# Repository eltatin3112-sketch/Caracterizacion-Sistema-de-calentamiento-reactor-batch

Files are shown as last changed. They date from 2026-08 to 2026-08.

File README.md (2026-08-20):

# CARACTERIZACIÓN TÉRMICA Y SINTONIZACIÓN PID DEL REACTOR BATCH - GRUPO 5
## Identificación Experimental Térmica y Dinámica de Sistemas - Sistemas de Control II (UNET)

Elaborado por: Daniel Torres y Yermey Castro

---

### 1. OBJETIVO DEL PROYECTO DE CARACTERIZACIÓN TÉRMICA
Este repositorio documenta la caracterización del lazo de calentamiento de un Reactor Batch a escala. Su objetivo es emular el acondicionamiento térmico de una mezcla farmacéutica utilizando una resistencia de inmersión de 110V AC.

El objetivo de esta fase en *Sistemas de Control II* es identificar experimentalmente los parámetros termodinámicos de la planta (Ganancia `K`, Constante de Tiempo `Tau` y Tiempo Muerto `Theta`) aplicando el método de la curva de reacción en lazo abierto. Estos datos son obligatorios para el posterior diseño y sintonización de un controlador PID que permita estabilizar el proceso de forma 

---

### 2. Hardware Mínimo Requerido

| Componente | Referencia / Modelo | Cantidad | Función en el sistema |
| :--- | :--- | :--- | :--- |
| **Microcontrolador** | ESP32 DevKit V1 | 1 | Procesamiento, temporización del SSR y servidor web. |
| **Sensor Térmico** | Sonda DS18B20 | 1 | Medición digital de temperatura en el fluido. |
| **Actuador Térmico**| Resistencia Inmersión | 1 | Aporte calórico (800W nominales). |
| **Interfaz Potencia**| Relé Estado Sólido SSR-50DA | 1 | Conmutación rápida de los 110V AC. |
| **Acoplamiento DC** | Transistor NPN 2N2222 | 1 | Interfaz de disparo de baja corriente para proteger el ESP32. |
| **Resistencias** | 4.7kΩ y 220Ω | 1 c/u | Pull-up para bus de datos (4.7k) y límite de base (220R). |
| **Fuentes de Poder** | ATX de PC y Cargador 5V| 1 c/u | ATX entrega 5V al SSR. Cargador aísla la lógica del ESP32. |

---

### 3. TABLA DE CONEXIONES Y PINOUT (CABLEADO CON ACOPLAMIENTO DE POTENCIA)
| Origen | Señal / Pin | Destino Hardware | Notas Técnicas de Conexión |
| :--- | :--- | :--- | :--- |
| ESP32 | `3V3` | DS18B20 `VCC` | Alimentación de sonda (Cable rojo). |
| ESP32 | `GPIO 04` | DS18B20 `DATA`| Bus One-Wire (Cable amarillo/azul). **Requiere R de 4.7kΩ a 3V3.** |
| ESP32 | `GPIO 18` | Transistor `Base`| Señal de disparo de calor (A través de R de 220Ω). |
| Transistor | `Emisor` | **GND COMÚN** | Pata izquierda hacia tierra. |
| Transistor | `Colector`| SSR `Pin 4 (-)`| Pata derecha. Disparo lógico (Conmuta el negativo). |
| Fuente ATX | `+5V` (Rojo) | SSR `Pin 3 (+)` | Alimenta el SSR directamente con 5V, evitando cargar al ESP32. |
| Red 110V AC | `Fase (Línea)` | SSR `Pin 1 (Load)` | Interrupción de la red de corriente alterna (Tras pasar por fusible). |
| SSR | `Pin 2 (Load)` | Resistencia | Retorno de fase conmutada hacia el calentador. |
| Red 110V AC | `Neutro` | Resistencia | Cierre del circuito AC directo al tomacorriente. |

*Nota sobre "Aislamiento":* El uso del transistor 2N2222 sirve como etapa de acoplamiento de corriente (driver) para evitar caídas de tensión en los pines del ESP32. Dado que el Emisor del transistor comparte el GND del ESP32 y de la fuente ATX, **no existe aislamiento galvánico en el lado de DC**, pero la electrónica de baja tensión queda protegida por el aislamiento óptico interno que posee el propio módulo SSR-50 DA respecto al lado de 110V AC.

*(El diagrama eléctrico detallado en formato .fzz de Fritzing se encuentra dentro de la carpeta `Diagrama electrico Caracterizacion temperatura` de este repositorio).*
---

### 4. Cómo Descargar, Instalar y Ejecutar desde Cero

### A. Preparación y Compilación
1. Descargue este repositorio (Botón **"Code" -> "Download ZIP"**) o clónelo vía Git.
2. Abra la carpeta en **Visual Studio Code** con la extensión **PlatformIO** instalada.
3. Asegúrese de que el archivo `platformio.ini` esté en la raíz e incluya las librerías `OneWire` y `DallasTemperature`.
4. Conecte el ESP32, abra la terminal de PIO y ejecute la carga del firmware:
   `pio run --target upload`

### B. Puesta en Marcha (¡Precaución!)
1. **Llene el reactor con al menos 2 Litros de agua ANTES de continuar.**
2. Enchufe la etapa de control (ESP32 a 5V). 
3. *Solo después de validar el nivel de agua*, enchufe la clavija de 110V AC a la pared.
4. Conéctese a la red WiFi **Reactor_Batch_G5** (`control_industrial`) e ingrese a **`http://192.168.4.1`**.
5. Desde la HMI, varíe la potencia térmica y monitorice la gráfica.
---

### 5. VALIDACIÓN DE LIBRERÍAS LOCALES (MODO OFFLINE)
Para garantizar el funcionamiento del banco de pruebas en entornos industriales o laboratorios sin acceso a internet (como los de la UNET), las librerías de visualización y exportación se cargan directamente desde la memoria interna del ESP32 (LittleFS).

Al ingresar a la interfaz en tu navegador (`192.168.4.1`), verifique el estado en la sección de diagnóstico:
*   **Chart.js local:** cargado
*   **SheetJS local (XLSX):** cargado
*   **Modo offline:** OK

*Nota:* Si alguna librería aparece como "no cargado", asegúrese de haber ejecutado con éxito el comando `uploadfs` en el Paso 3 de la sección anterior.

---

### 6. PROCEDIMIENTO DEL ENSAYO DE CARACTERIZACIÓN TÉRMICA (LAZO ABIERTO)
Este protocolo experimental se ejecutó en **Lazo Abierto** (sin algoritmo de control automático en el ESP32, operando de forma manual la potencia del SSR al 100%) para capturar las curvas de reacción térmicas y analizar los gradientes del fluido:

#### Etapa 1: Ensayos de Homogeneidad Espacial (Sensor en 3 Profundidades)
Para comprobar si la agitación mecánica es efectiva para eliminar los gradientes térmicos, se realizaron tres pruebas secuenciales idénticas bajo una carga de 2 Litros de agua y agitación constante al 50% de PWM, moviendo la altura del sensor DS18B20:
1.  **Prueba A (Fondo):** Fijar la sonda al fondo del tanque (cerca de la resistencia). Resultado: Alcanzó los 40C en **2:51 minutos**.
2.  **Prueba B (Zona Media):** Fijar la sonda en el centro geométrico del fluido. Resultado: Alcanzó los 40C en **2:48 minutos**.
3.  **Prueba C (Superficie):** Fijar la sonda cerca de la superficie del agua. Resultado: Alcanzó los 40C en **2:42 minutos**.
*   **Análisis de Homogeneidad:** La diferencia de apenas **9 segundos** entre el punto más lento y el más rápido valida que la mezcla forzada homogeneiza la temperatura, aproximando el reactor al modelo de parámetros concentrados (mezcla perfecta).

#### Etapa 2: Ensayo de Convección Natural (Motor al 0%) vs. Forzada (Motor al 100%)
1.  **Convección Natural (Motor al 0%):** Con el agitador apagado, aplicar un escalón del 100% de potencia térmica y registrar la curva de temperatura.
2.  **Convección Forzada (Motor al 100%):** Con el motor a máxima velocidad (255 PWM), aplicar el mismo escalón y registrar la curva.
*   **Análisis:** Se demostró que al incrementar la velocidad de agitación se reduce el tiempo muerto (Theta) y disminuye la constante de tiempo (Tau), ya que aumenta el coeficiente global de transferencia de calor (U).

#### Etapa 3: Ensayo de Variación de Masa Térmica (Efecto de Carga)
1.  Cargar el reactor con **3 Litros de agua** (agitación al 100% PWM).
2.  Aplicar un escalón del 100% de calor, registrar la curva de temperatura y descargar el archivo de datos.
*   **Análisis:** Al aumentar el volumen un 50%, la constante de tiempo (Tau) aumentó un 46% (pasando de 92s a 135s), demostrando que la inercia térmica es altamente sensible a la masa del fluido.

---

### 7. PROYECCIÓN AL DISEÑO DEL CONTROLADOR PID EN MATLAB
Los datos crudos recolectados en estos ensayos en lazo abierto permitieron modelar matemáticamente la planta y calcular los parámetros del controlador que se implementarán en la fase de control automático (Tema 4):

*   **Parámetros FOPDT Identificados (Caso 2 Litros):** 
    *   Ganancia (K): 0.18 grados/%.
    *   Constante de tiempo (Tau): 92 segundos.
    *   Tiempo Muerto (Theta): 6 segundos.
*   **Cálculo Teórico de Cohen-Coon:**
    *   **Ganancia Proporcional (Kp):** 114.7
    *   **Tiempo Integral (Ti):** 14.6 segundos
    *   **Tiempo Derivativo (Td):** 2.1 segundos
*   **Sintonización Fina y Simulación en MATLAB:**
    Al simular el modelo teórico en MATLAB, se identificó que la ganancia de 114.7 causaba un sobreimpulso crítico de 17.5C (llegando a 62.5C), lo que degradaría el producto farmacéutico. Por ello, se realizó un ajuste fino conservador en MATLAB para lograr un "aterrizaje" suave de temperatura a los 45C sin sobrepasos, sintonizando el PID final con: **Kp = 35.0, Ki = 0.024 (Ti = 40s) y Kd = 5.0 (Td = 5s)**.

---

### 8. INTERPRETACIÓN DE RESULTADOS OBTENIDOS (ANÁLISIS)
A partir del procesamiento de los datos descargados en formato CSV de las pruebas de lazo abierto y su modelado en MATLAB, se identificaron los siguientes comportamientos termodinámicos:

#### A. Ganancia Térmica (K) y Eficiencia del Calefactor
Se identificó una ganancia constante de **0.18 grados Celsius / % de potencia** para ambas cargas (2L y 3L). Esto demuestra que la ganancia es una propiedad estática ligada estrictamente a la potencia de la resistencia de inmersión y a las pérdidas de calor ambientales. El sistema es altamente eficiente, permitiendo predecir que con el 100% de potencia el reactor es térmicamente capaz de superar con creces la meta de 45C de diseño.

#### B. Impacto de la Masa en la Constante de Tiempo (Tau)
Los ensayos de carga demostraron la alta sensibilidad del reactor a la masa térmica:
*   **Con 2 Litros:** La constante de tiempo (Tau) fue de **92 segundos**.
*   **Con 3 Litros:** Al aumentar el volumen en un 50%, la constante de tiempo subió a **135 segundos (un incremento del 46%)**.
*   **Análisis:** Esto confirma experimentalmente que la velocidad de respuesta del reactor es inversamente proporcional al volumen de fluido acumulado (Vessel Holdup), lo que requiere que el futuro controlador PID sea sintonizado considerando el peor escenario de inercia (3L) para evitar oscilaciones en cargas menores.

#### C. Variación del Tiempo Muerto (Theta) por Profundidad del Sensor
Se demostró que el retardo de transporte (tiempo muerto) no es una constante electrónica, sino una variable física influenciada por la hidrodinámica del tanque:
*   **Sensor en el Fondo (Cerca de resistencia):** Registró un tiempo de 2 minutos 51 segundos para llegar a 40C.
*   **Sensor en la Superficie (Lejos de resistencia):** Registró un tiempo de 2 minutos 42 segundos.
*   **Análisis:** Al estar el motor encendido, se genera un flujo ascendente de agua caliente por convección forzada que sube rápidamente, lo que explica por qué la superficie calienta ligeramente más rápido (9 segundos de diferencia). Esta brecha mínima valida experimentalmente que la agitación destruye de forma efectiva los gradientes térmicos y permite asumir un modelo de **mezcla perfecta**.

#### D. Comparativa Dinámica del PID en Lazo Cerrado (MATLAB)
Al simular la sintonización del PID en MATLAB para analizar el comportamiento del lazo cerrado en el futuro diseño de control, se obtuvieron las siguientes conclusiones:
*   **Cohen-Coon Teórico (Agresivo):** Al aplicar $Kp = 114.7$, el sistema responde de forma violenta, provocando un sobreimpulso térmico crítico de **17.5 grados Celsius (alcanzando una temperatura pico de 62.5C)** que degradaría químicamente la solución farmacéutica.
*   **Sintonización Fina Suave (Cargada en el ESP32):** Al reducir la ganancia a **$Kp = 35.0$**, aumentar el tiempo integral a **$Ti = 40.0s$** ($Ki=0.024$) y la acción derivativa a **$Td = 5.0s$**, la temperatura real se estabiliza de forma plana en 45C en **150 segundos (2.5 minutos)** con un sobreimpulso seguro de solo **2.0 grados Celsius** (pico de 47C) y error estacionario cero.

  ---

   9. Problemas Frecuentes (Troubleshooting)

*   **El sensor marca `-127.0 C` o se congela el sistema:** El cable de datos del DS18B20 está suelto o falta colocar la resistencia de Pull-Up de 4.7kΩ entre VCC y DATA.
*   **La página web no carga:** Ocurre si el ESP32 se "atasca" esperando respuesta del sensor térmico. Revise las conexiones del sensor y asegúrese de que el código tenga la función `sensors.setWaitForConversion(false)` para un manejo asíncrono.
*   **El SSR no se enciende (LED del SSR apagado):** Revise que la fuente ATX esté suministrando 5V al Pin 3 del SSR y que el transistor 2N2222 esté conectado con la polaridad correcta (Emisor a GND, Colector al SSR).
*   **El SSR se enciende pero el agua no calienta:** Falla en la etapa de potencia AC. Revise si se quemó el fusible de 10A o si el tomacorriente de pared tiene suministro.

  ---

 10. ADVERTENCIA CRÍTICA DE SEGURIDAD (110V AC)
**¡PELIGRO DE ELECTROCUCIÓN Y QUEMADURAS SEVERAS!**
Este circuito maneja voltajes letales de la red doméstica (110V AC) y corrientes cercanas a los 7.5 Amperios.
*   **Aislamiento AC:** La etapa de 110V debe estar en un bloque de terminales protegido. **NUNCA toque los bornes del SSR (Pines 1 y 2) ni la resistencia de inmersión mientras el equipo esté conectado al tomacorriente.**
*   **Marcha en Seco:** NUNCA encienda la resistencia eléctrica de inmersión si no está completamente cubierta por al menos 1.0 Litro de agua. Si se enciende en el aire, se fundirá en segundos y puede causar un incendio.
*   **Protección por Fusible:** Es obligatorio colocar un **fusible de 10A de acción rápida** en serie con el cable de Fase (Línea) antes de entrar al SSR.
*   **Apagado Seguro:** En caso de emergencia, la desconexión debe hacerse desenchufando físicamente la clavija de 110V de la pared, no confiando únicamente en la interrupción lógica del SSR.

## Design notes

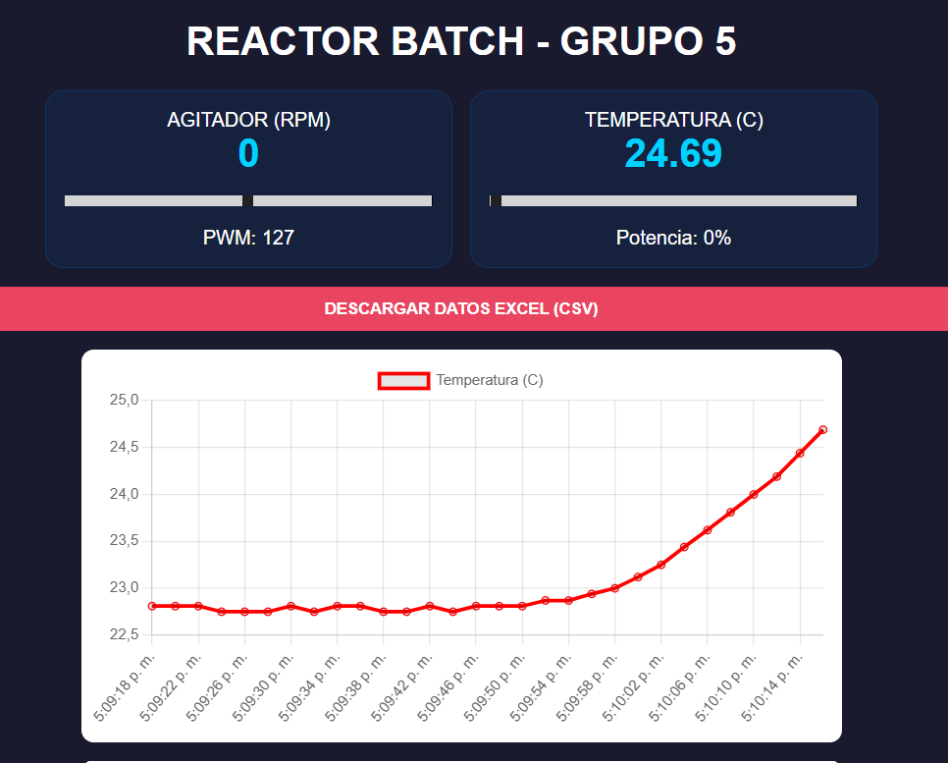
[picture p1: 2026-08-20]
Graficas obtenidas del sistema de calentamiento/Comportamiento inicial de la temperatura.png

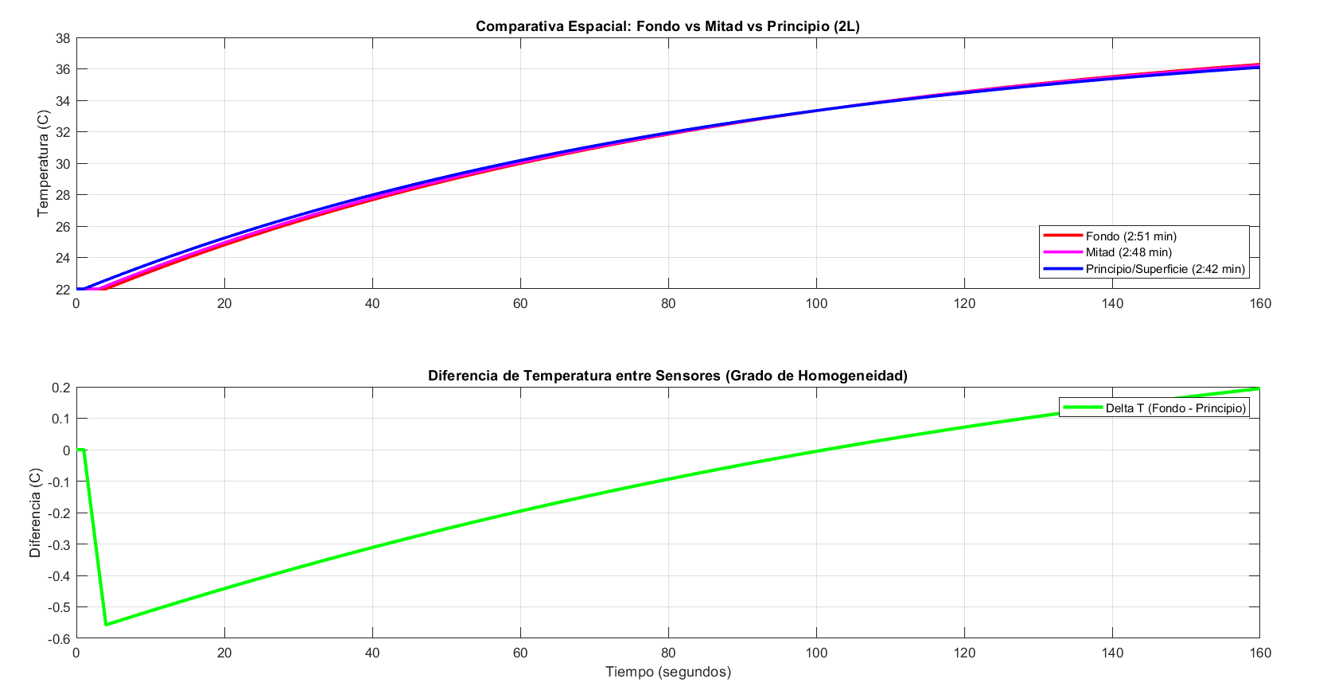
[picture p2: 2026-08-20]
Graficas obtenidas del sistema de calentamiento/Grafica de diferencia de temperatura con posicionamiento de los sensores.png

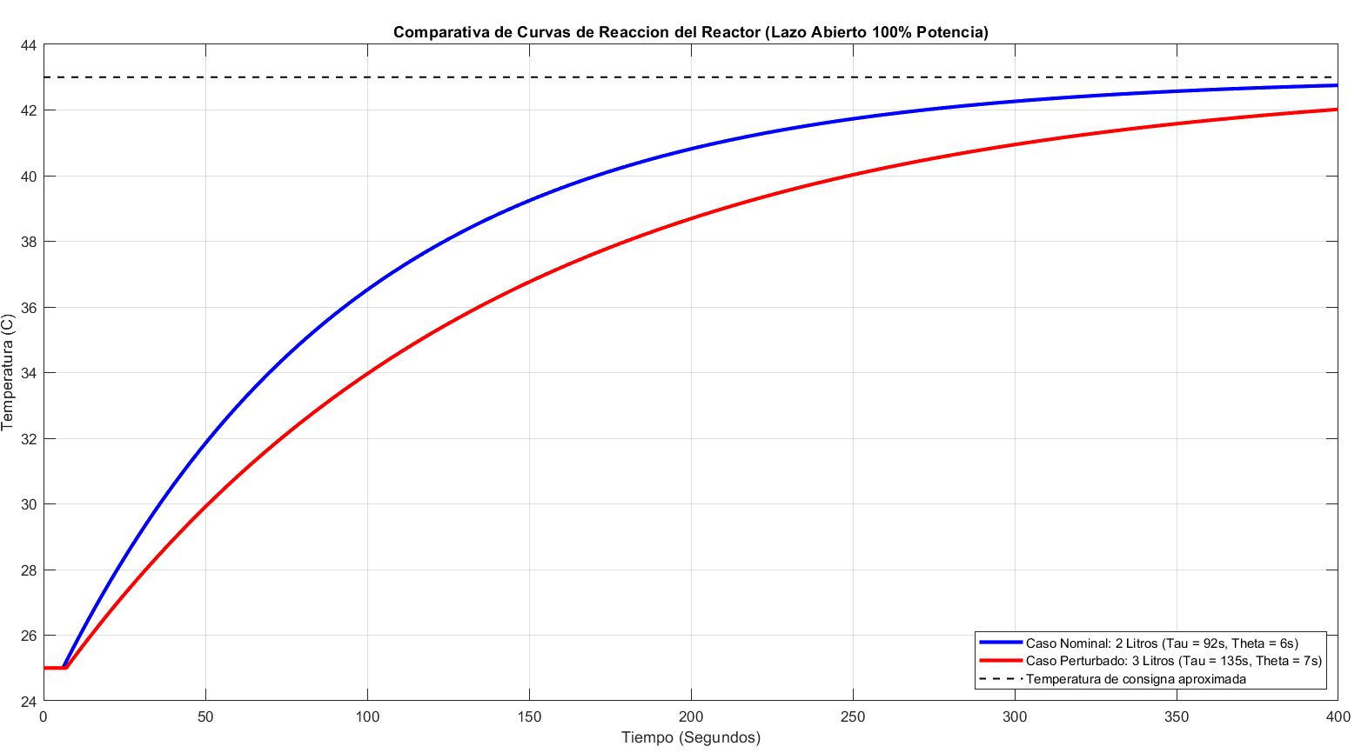
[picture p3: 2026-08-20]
Graficas obtenidas del sistema de calentamiento/Grafica Comparativa de calentamiento con carga de 2 y 3L .png

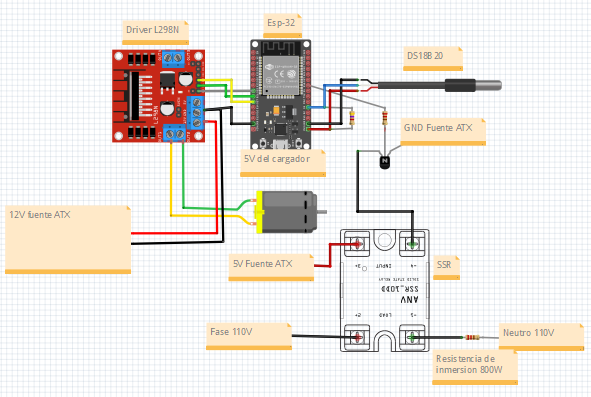
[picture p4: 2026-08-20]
Diagrama electrico Caracterizacion temperatura/Diagrama electrico Caracterizacion temperatura.png

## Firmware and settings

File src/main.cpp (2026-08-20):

#include <Arduino.h>
#include <WiFi.h>
#include <ESPAsyncWebServer.h>
#include <OneWire.h>
#include <DallasTemperature.h>

// --- PINES ---
const int PIN_DS18B20 = 4;
const int PIN_ENCODER = 33;
const int PIN_MOTOR_ENA = 25;
const int PIN_MOTOR_IN1 = 26;
const int PIN_MOTOR_IN2 = 27;
const int PIN_SSR = 18;

OneWire oneWire(PIN_DS18B20);
DallasTemperature sensors(&oneWire);
AsyncWebServer server(80);

// Variables de sensores
float temperatura = 0.0;
volatile int pulsos = 0;
int rpm = 0;
int current_pwm = 0;

unsigned long tiempo_anterior = 0;
String log_datos = "Tiempo(s),PWM,RPM,Temperatura(C)\n";
unsigned long inicio_ms = 0;

void IRAM_ATTR contarPulsos() { pulsos++; }

const char index_html[] PROGMEM = R"rawliteral(
<!DOCTYPE HTML><html>
<head>
    <title>Reactor Batch G5</title>
    <meta name="viewport" content="width=device-width, initial-scale=1">
    <script src="https://cdn.jsdelivr.net/npm/chart.js"></script>
    <style>
        body { font-family: sans-serif; background: #1a1a2e; color: white; padding: 20px; text-align: center; }
        .container { display: flex; flex-wrap: wrap; justify-content: center; gap: 15px; }
        .card { background: #16213e; border-radius: 15px; padding: 15px; width: 300px; border: 1px solid #0f3460; }
        .data-val { font-size: 32px; font-weight: bold; color: #00d2ff; }
        .slider { width: 100%; margin: 15px 0; }
        .btn { background: #e94560; color: white; border: none; padding: 10px; border-radius: 5px; cursor: pointer; width: 100%; font-weight: bold; }
        .chart-box { background: white; border-radius: 10px; margin: 15px auto; padding: 10px; max-width: 600px; }
    </style>
</head>
<body>
    <h1>REACTOR BATCH - GRUPO 5</h1>
    <div class="container">
        <div class="card">
            <div>AGITADOR (RPM)</div>
            <div id="rpm_val" class="data-val">0</div>
            <input type="range" min="0" max="255" value="0" class="slider" oninput="updateMotor(this.value)">
            <div>PWM: <span id="pwm_label">0</span></div>
        </div>
        <div class="card">
            <div>TEMPERATURA (C)</div>
            <div id="temp_val" class="data-val">0.0</div>
            <input type="range" min="0" max="100" value="0" class="slider" oninput="updateHeat(this.value)">
            <div>Potencia: <span id="heat_label">0</span>%</div>
        </div>
    </div>
    <div style="margin-top:15px;"><button class="btn" onclick="downloadData()">DESCARGAR DATOS EXCEL (CSV)</button></div>
    
    <div class="chart-box"><canvas id="tempChart"></canvas></div>
    <div class="chart-box"><canvas id="rpmChart"></canvas></div>

    <script>
        function updateMotor(v) { document.getElementById('pwm_label').innerHTML = v; fetch('/set_pwm?v=' + v); }
        function updateHeat(v) { document.getElementById('heat_label').innerHTML = v; fetch('/set_heat?v=' + v); }
        function downloadData() { window.location.href = "/download"; }

        function createChart(id, label, color) {
            return new Chart(document.getElementById(id), {
                type: 'line',
                data: { labels: [], datasets: [{ label: label, borderColor: color, data: [], fill: false }] },
                options: { responsive: true, animation: false }
            });
        }
        var tChart = createChart('tempChart', 'Temperatura (C)', 'red');
        var rChart = createChart('rpmChart', 'Velocidad (RPM)', 'blue');

        setInterval(function() {
            fetch('/data').then(res => res.json()).then(data => {
                document.getElementById('rpm_val').innerHTML = data.rpm;
                document.getElementById('temp_val').innerHTML = data.temp;
                let t = new Date().toLocaleTimeString();
                [tChart, rChart].forEach((c, i) => {
                    c.data.labels.push(t);
                    c.data.datasets[0].data.push(i==0 ? data.temp : data.rpm);
                    if(c.data.labels.length > 30) { c.data.labels.shift(); c.data.datasets[0].data.shift(); }
                    c.update();
                });
            });
        }, 2000);
    </script>
</body>
</html>)rawliteral";

void setup() {
    Serial.begin(115200);
    pinMode(PIN_MOTOR_ENA, OUTPUT); pinMode(PIN_MOTOR_IN1, OUTPUT); pinMode(PIN_MOTOR_IN2, OUTPUT);
    pinMode(PIN_SSR, OUTPUT); pinMode(PIN_ENCODER, INPUT_PULLUP);
    sensors.begin();
    attachInterrupt(digitalPinToInterrupt(PIN_ENCODER), contarPulsos, RISING);
    WiFi.softAP("Reactor_Batch_G5", "control_industrial");
    inicio_ms = millis();

    server.on("/", HTTP_GET, [](AsyncWebServerRequest *request){ request->send_P(200, "text/html", index_html); });
    
    server.on("/set_pwm", HTTP_GET, [](AsyncWebServerRequest *request){
        if (request->hasParam("v")) {
            current_pwm = request->getParam("v")->value().toInt();
            digitalWrite(PIN_MOTOR_IN1, HIGH); digitalWrite(PIN_MOTOR_IN2, LOW);
            analogWrite(PIN_MOTOR_ENA, current_pwm);
        }
        request->send(200, "text/plain", "OK");
    });

    server.on("/set_heat", HTTP_GET, [](AsyncWebServerRequest *request){
        if (request->hasParam("v")) {
            digitalWrite(PIN_SSR, request->getParam("v")->value().toInt() > 0 ? HIGH : LOW);
        }
        request->send(200, "text/plain", "OK");
    });

    server.on("/data", HTTP_GET, [](AsyncWebServerRequest *request){
        request->send(200, "application/json", "{\"temp\":" + String(temperatura) + ",\"rpm\":" + String(rpm) + "}");
    });

    server.on("/download", HTTP_GET, [](AsyncWebServerRequest *request){
        request->send(200, "text/csv", log_datos);
    });

    server.begin();
}

void loop() {
    if (millis() - tiempo_anterior >= 1000) {
        rpm = (pulsos * 60) / 20;
        pulsos = 0;
        sensors.requestTemperatures();
        temperatura = sensors.getTempCByIndex(0);
        
        // Guardar en el LOG para el CSV
        log_datos += String((millis()-inicio_ms)/1000) + "," + String(current_pwm) + "," + String(rpm) + "," + String(temperatura) + "\n";
        
        tiempo_anterior = millis();
    }
}
